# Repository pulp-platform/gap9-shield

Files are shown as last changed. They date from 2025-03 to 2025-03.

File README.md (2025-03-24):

# GAP9Shield: An AI-Capable Ultra-Low Power Module for Nano-Drones  

## Introduction  
The **GAP9Shield** is a state-of-the-art hardware module designed to enhance the performance of nano-drones, enabling advanced vision-based and ranging applications. Powered by the **GAP9 System-on-Chip (SoC)**, this platform delivers unparalleled AI processing capabilities and energy efficiency. With its compact design and cutting-edge features, GAP9Shield revolutionizes the potential of nano-drones, particularly for indoor environments and close-proximity interactions with humans.  

GAP9Shield mounted on a Craziflie 2.1

---

## Features and Specifications  

### Core Processor: GAP9 SoC  
- **Architecture**: 9-core RISC-V cluster with AI acceleration (NE16).  
- **Performance**: 15.6 GOPs for DSP, 32.2 GMACs for ML tasks.  
- **Energy Efficiency**: 330 µW/GOP.  
- **Dynamic Scaling**: Frequency up to 370 MHz, sleep power as low as 45 µW.  
- **Memory**:  
  - 1.6 MB L2 RAM and 2 MB embedded non-volatile memory.  
  - Additional 256 Mbit PSRAM and 512 Mbit Flash.  

### Camera: OV5647 Sensor  
- **Resolution**: 5 MP, supporting QSXGA to QVGA formats.  
- **Frame Rates**: Up to 120 fps (QVGA).  
- **Interface**: CSI2 single-line connectivity.  

### Connectivity: NINA-W102 Wi-Fi/BLE Module  
- **Processor**: ESP32 dual-core MCU.  
- **Wireless Capability**: 2.4 GHz Wi-Fi and Bluetooth.  
- **Throughput**: Up to 12 Mbps (UDP) with low power consumption.  

### Ranging System: 5D VL53L1 Array  
- **Directionality**: Covers right, left, front, back, and upward directions.  
- **Range**: Up to 400 cm with a sampling rate of 60 Hz.  

### Physical Characteristics  
- **Dimensions**: 50 mm x 27 mm (6-layer PCB).  
- **Weight**: Approx. 6 grams.  

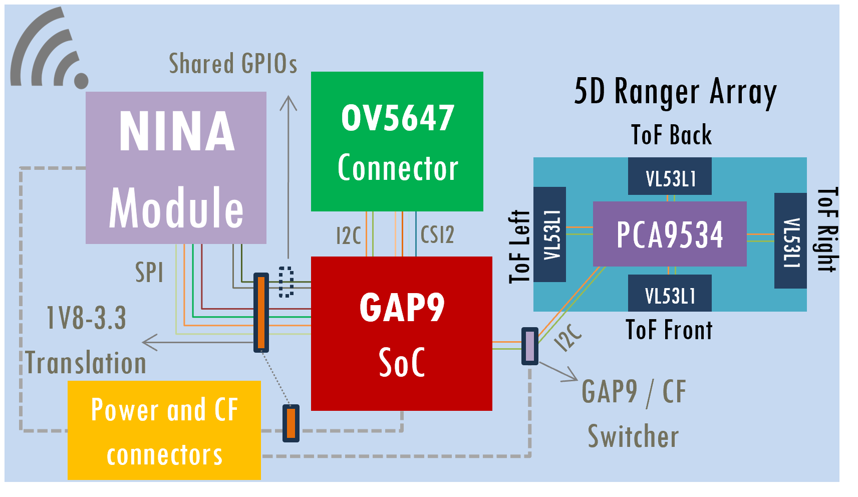
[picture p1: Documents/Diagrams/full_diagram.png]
Block diagram of GAP9Shield


---

## Key Advantages  

### Performance  
- 20% higher frame rate for RGB images compared to conventional AI-decks.  
- Optimized for AI workloads like YOLO object detection, MCL localization, and SLAM.  

### Energy Efficiency  
- Operates below 100 mW for most tasks.  
- Designed for extended flight durations with lightweight, power-efficient components.  

### Versatility  
- Compatible with high-definition cameras via MIPI CSI2.  
- Integrated Wi-Fi and BLE modules for seamless data streaming and communication.  

### Compact and Lightweight  
- 15% lighter and 30% smaller than comparable setups.  

---

## Applications  
The GAP9Shield is ideal for:  
- Obstacle avoidance in confined spaces.  
- Real-time object detection and mapping.  
- Greenhouse farming and industrial inspections.  
- Precise image recognition and navigation in cluttered environments.  

---

## Repository Organization
1. Hardware: Contains the hardware files for the shield.
1.1 gap9_deck_v2: Contains the design files (Altium) for the shield.
1.2 ToF-FrontBack: Contains the design files (Altium) for the ToF PCBs (front and back). These need to be mounted first and then soldered to the main PCB.
1.3 ToF-LeftRight: Contains the design files (Altium) for the ToF PCBs (Right and left). These need to be mounted first and then soldered to the main PCB.

2. Firmware: will contain firmware files (future release).

3. Documents: Contains the repository documentation.
3.1 Schematics: Main PCB and accesory PCB schematics in PDF format.
3.2 Pictures: Images/3D models of the shield.
3.3 Diagrams: GAP9shield diagrams.

---

## Acknowledges

If you use the **GAP9shield** in an academic or industrial context, please cite the following publication:

~~~~
@InProceedings{muller2024gap9shield,
author="M{\"u}ller, Hanna
and Kartsch, Victor
and Benini, Luca",
title="GAP9Shield: A 150GOPS AI-Capable Ultra-low Power Module for Vision and Ranging Applications on Nano-drones",
booktitle="European Robotics Forum 2024",
year="2024",
publisher="Springer Nature Switzerland",
address="Cham",
pages="292--297",
isbn="978-3-031-76424-0"
}
~~~~

# License

This project is open source. 

The files within the following folder (and subfolders) are released under Solderpad v0.51 (`SHL-0.51`) (see [LICENSE](LICENSE.txt)):

- `Hardware/`

The files within the following folder (and subfolders) are released under Creative Commons Attribution 4.0 International
License (`CC-BY-4.0`) (see [Documents/LICENSE](Documents/LICENSE)):

- `Documents/`

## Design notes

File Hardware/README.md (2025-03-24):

# GAP9Shield Hardware Documentation  

## Introduction  
This section provides all the necessary design files and resources for the hardware development of the **GAP9Shield**, a high-performance, low-power module designed for AI-driven applications on nano-drones. The GAP9Shield hardware is designed to optimize performance for nano-drones while maintaining a lightweight and compact form factor. Key features include:  
- **High-Performance ToF Sensors**: Enable obstacle avoidance and environmental mapping with high accuracy and low latency.  
- **GAP9 SoC Integration**: Ensures efficient processing for AI workloads with ultra-low power consumption.  
- **Easy Assembly**: Modular design allows for straightforward assembly and soldering.
 
 he hardware integrates multiple components, including the GAP9 SoC, a high-definition camera, and a 5D ranging array. The provided resources are organized into three folders, detailed below. 

---

## Folder Structure  

### 1. Hardware  
The `Hardware` folder contains all the design files necessary for the GAP9Shield and its associated subsystems. Each folder includes files created in **Altium Designer**, enabling straightforward editing and fabrication.

#### 1.1 gap9_deck_v2  
- **Description**: This folder contains the complete design files for the main shield PCB, integrating the GAP9 SoC, NINA-W102 Wi-Fi/BLE module, and OV5647 camera.  
- **Features**:  
  - 6-layer PCB with dimensions of 50mm x 27mm.  
  - Optimized layout for compactness and power efficiency.  
  - Interfaces for the ToF subsystems and external peripherals.

#### 1.2 ToF-FrontBack  
- **Description**: This folder contains design files for the **front** and **back** Time-of-Flight (ToF) sensor PCBs.  
- **Notes**:  
  - PCBs use the VL53L1 laser-based ToF sensors.  
  - These sensors enable precise distance measurements of up to 400 cm.  
  - These PCBs must be mounted first and soldered to the main PCB.

#### 1.3 ToF-LeftRight  
- **Description**: This folder contains design files for the **left** and **right** ToF sensor PCBs.  
- **Notes**:  
  - Utilizes the same VL53L1 ToF sensors as the front and back PCBs.  
  - These PCBs must also be mounted and soldered to the main PCB.  

---

For additional details, contact the development team.

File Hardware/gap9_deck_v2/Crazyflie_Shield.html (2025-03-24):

Altium customize

# Board Information Report

Date: | | 5/30/2022
Time: | | 4:37:14 PM
Elapsed Time: | | 00:00:00
Filename: | | C:\noOneDrive\FFG9_HW_CF_deck\gap9_deck\Crazyflie_Shield.PcbDoc
Units: | | mmmils

## Contents

Contents

Layer Information

Layer Information

Other

Pad Pwr/Gnd Expansion

## Layer Information

Layer | Arcs | Pads | Vias | Tracks | Texts | Fills | Regions | ComponentBodies
F.Cu | 3 | 179 | 0 | 306 | 0 | 0 | 7 | 0
Layer 1 | 0 | 0 | 0 | 14 | 0 | 0 | 1 | 0
Layer 2 | 0 | 0 | 0 | 53 | 0 | 0 | 5 | 0
B.Cu | 0 | 144 | 0 | 309 | 0 | 0 | 0 | 0
B.Adhes | 0 | 0 | 0 | 0 | 0 | 0 | 0 | 1
Top 3D Body | 0 | 0 | 0 | 28 | 0 | 0 | 0 | 7
Top Courtyard | 0 | 0 | 0 | 28 | 0 | 0 | 0 | 0
Top Assembly | 0 | 0 | 0 | 28 | 7 | 0 | 0 | 0
Eco1.User | 10 | 0 | 0 | 1830 | 13 | 0 | 0 | 0
Mechanical 12 | 0 | 0 | 0 | 12 | 0 | 0 | 0 | 0
Mechanical 13 | 0 | 0 | 0 | 100 | 0 | 0 | 0 | 44
Mechanical 15 | 0 | 0 | 0 | 222 | 0 | 0 | 0 | 0
Top Component Center | 0 | 0 | 0 | 14 | 0 | 0 | 0 | 0
Bottom Assembly | 0 | 0 | 0 | 4 | 1 | 0 | 0 | 0
Bottom Courtyard | 0 | 0 | 0 | 4 | 0 | 0 | 0 | 0
Bottom 3D Body | 0 | 0 | 0 | 4 | 0 | 0 | 0 | 1
Bottom Component Center | 0 | 0 | 0 | 2 | 0 | 0 | 0 | 0
Multi-Layer | 0 | 22 | 96 | 0 | 0 | 0 | 2 | 0
F.Paste | 0 | 0 | 0 | 0 | 0 | 0 | 0 | 0
F.SilkS | 5 | 0 | 0 | 35 | 55 | 0 | 0 | 0
F.Mask | 5 | 0 | 0 | 0 | 0 | 0 | 7 | 0
B.Mask | 0 | 0 | 0 | 0 | 0 | 0 | 0 | 0
B.SilkS | 7 | 0 | 0 | 61 | 85 | 0 | 0 | 0
B.Paste | 0 | 0 | 0 | 0 | 0 | 0 | 0 | 0
Drill Guide | 0 | 0 | 0 | 0 | 0 | 0 | 0 | 0
Edge.Cuts | 0 | 0 | 0 | 0 | 0 | 0 | 0 | 0
Drill Drawing | 0 | 0 | 0 | 0 | 0 | 0 | 0 | 0
Total | 30 | 345 | 96 | 3054 | 161 | 0 | 22 | 53

Back to top

## Other

Pad Pwr/Gnd Expansion | Count
0.2mm | 345
Total | 345

Back to top

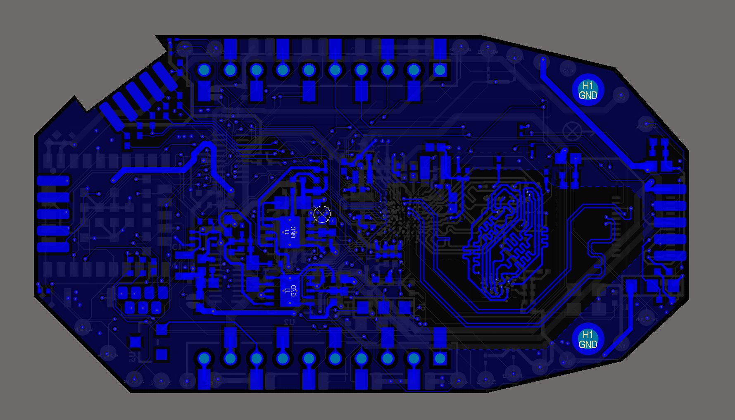
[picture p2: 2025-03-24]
Documents/Pictures/Renderings/2D/boton_2d.png

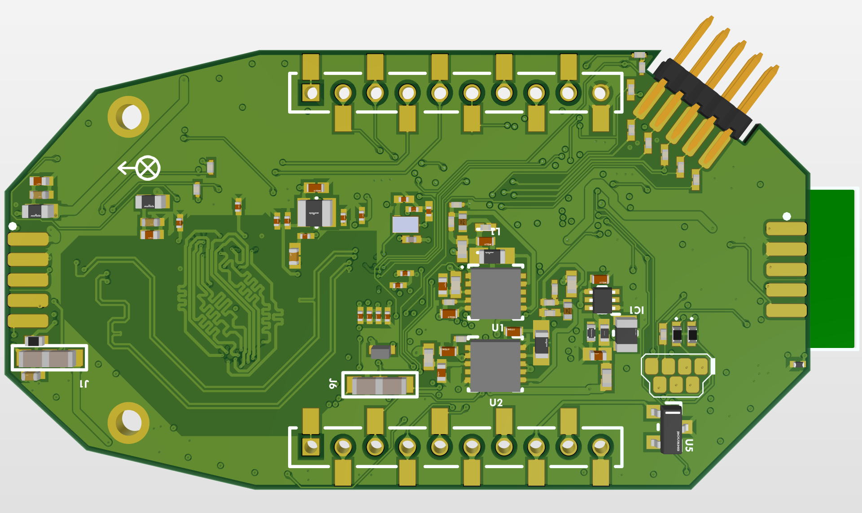
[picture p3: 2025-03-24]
Documents/Pictures/Renderings/3D/3D_bottom.png

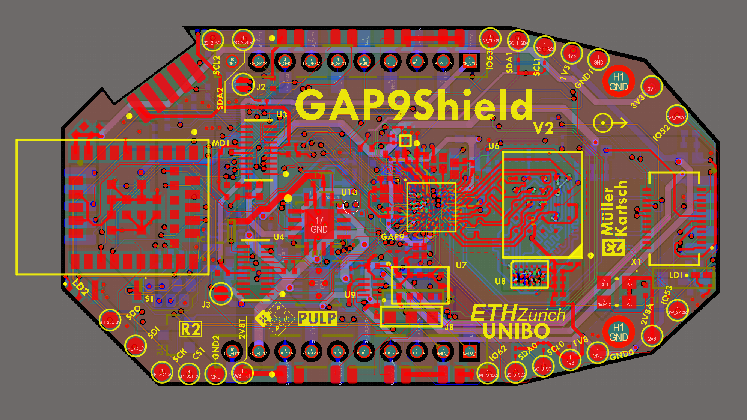
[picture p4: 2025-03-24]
Documents/Pictures/Renderings/2D/top_2d.png

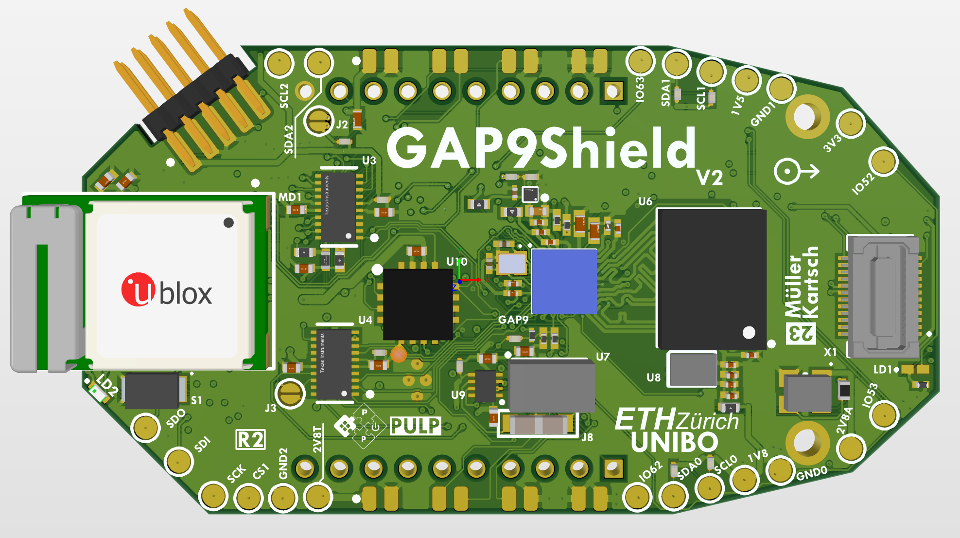
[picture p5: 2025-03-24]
Documents/Pictures/Renderings/3D/3D_top.png

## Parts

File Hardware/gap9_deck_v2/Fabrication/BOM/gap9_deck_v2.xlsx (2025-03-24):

Line # | Name | Description | Designator | Quantity | Manufacturer 1 | Manufacturer Part Number 1 | Manufacturer Lifecycle 1 | Supplier 1 | Supplier Part Number 1 | Supplier Unit Price 1 | Supplier Subtotal 1
 | 100K 1% 0201(0603) | 100K 0.05W 1% 0201 (0603 Metric) SMD | R37 | 1 | Panasonic | ERJ-1GNF1003C | Volume Production | Newark | 85Y7485 | 0.00371 | 0.00371
 | 150040GS73220 | LED | LD2 | 1 | Wurth Electronics | 150040GS73220 | Volume Production | Mouser | 710-150040GS73220 | 0.47271 | 0.47271
 | APHHS1005LSECK/J3-PF | LED | LD1 | 1 | Kingbright | APHHS1005LSECK/J3-PF | Volume Production | Arrow Electronics | APHHS1005LSECK/J3-PF | 0.40978 | 0.40978
 | APS256XXN-OBR-WA | No Description Available | U8 | 1 | Provided by client | Provided by client | Provided by client | Provided by client | Provided by client | Provided by client | Provided by client
 | BLM18HE152SN1D | Chip Ferrite Bead, 0603, 1500Ω @ 100MHz, 0.5Ω, 25%, 500mA | FB1, FB2 | 2 | Murata | BLM18HE152SN1D | Volume Production | Mouser | 81-BLM18HE152SN1D | 0.17611 | 0.35222
 | C1005X5R0J475K050BC | CAP CER 4.7UF 6.3V X5R 0402 | C24, C49, C55 | 3 | TDK | C1005X5R0J475K050BC | Volume Production | Newark | 79Y4179 | 0.07137 | 0.21411
 | CBL2012T1R0M | FIXED IND 1UH 950MA 195 MOHM SMD | L3 | 1 | Taiyo Yuden | CBL2012T1R0M | Not Recommended for New Design | Digi-Key | 587-1629-1-ND | 0.23172 | 0.23172
 | CBR02C200F5GAC | No Description Available | C39, C40 | 2 | KEMET | CBR02C200F5GAC | Volume Production | Newark | 96Y6792 | 0.11493 | 0.22987
 | CC0402KRX7R7BB103 | CAP CER 10000PF 16V X7R 0402 | C10, C11, C13 | 3 | Yageo | CC0402KRX7R7BB103 | Volume Production | Newark | 65R7669 | 0.00185 | 0.00556
 | CL03A105KP3NSNC | Cap Ceramic 1uF 10V X5R ±10% Pad SMD 0201 +85°C T/R | C23 | 1 | Samsung | CL03A105KP3NSNC | Volume Production | Digi-Key | 1276-6795-1-ND | 0.25953 | 0.25953
 | CL05A106MP5NUNC | CAP CER 10UF 10V X5R 0402 | C32, C63 | 2 | Samsung | CL05A106MP5NUNC | Not Recommended for New Design | Newark | 82AC9190 | 0.02873 | 0.05747
 | DNM |  | P1 | 1 | Do not mount | Do not mount | Do not mount | Do not mount | Do not mount | Do not mount | Do not mount
 | DNM |  | P2 | 1 | Do not mount | Do not mount | Do not mount | Do not mount | Do not mount | Do not mount | Do not mount
 | CRCW02014K99FKED |  | R3, R9 | 2 | Vishay Dale | CRCW02014K99FKED | Volume Production | Mouser | 71-CRCW02014K99FKED | 0.22245 | 0.4449
 | CRCW020110K0FNED |  | R1, R7, R11, R20, R22, R23, R27, R28, R45, R46, R47, R48, R49, R50, R51, R52, R54 | 17 | Vishay | CRCW020110K0FNED | Volume Production | Newark | 72W1407 | 0.00649 | 0.1103
 | CRCW020164K9FKED |  | R5 | 1 | Panasonic | ERJ-1GNF6492C | Volume Production | Digi-Key | P123116CT-ND | 0.09269 | 0.09269
 | CRCW020180K6FNED |  | R21 | 1 | Vishay | CRCW020180K6FNED | Volume Production | Digi-Key | 541-CRCW020180K6FNEDCT-ND | 0.09269 | 0.09269
 | CRCW0201200KFKED |  | R2, R8 | 2 | Vishay Dale | CRCW0201200KFKED | Volume Production | Newark | 84AH5178 | 0.13069 | 0.26138
 | CRCW0201220RFKED |  | R14, R15, R16, R17, R18, R19, R24 | 7 | Vishay Dale | CRCW0201220RFKED | Volume Production | Arrow Electronics | CRCW0201220RFKED | 0.13329 | 0.933
 | CRCW04020000Z0EDC | RES 0 OHM JUMPER 1/16W 0402 | R44 | 1 | Vishay | CRCW04020000Z0EDC | Volume Production | Mouser | 71-CRCW04020000Z0EDC | 0.09269 | 0.09269
 | DF30FC-24DS-0.4V(81) | Board Connector, 24 Contact(s), 2 Row(s), Female, Straight, 0.016 inch Pitch, Surface Mount Terminal, Locking, Black Insulator, Receptacle | X1 | 1 | Hirose | DF30FC-24DS-0.4V(81) | Volume Production | Mouser | 798-DF30FC24DS04V81 | 0.95469 | 0.95469
 | DFE201610E-4R7M=P2 | Shielded Wirewound Inductor 4.7uH 20% 1100mA 0.288Ω 0806 (2016) | L7 | 1 | Murata | DFE201610E-4R7M=P2 | Volume Production | Digi-Key | 490-18108-1-ND | 0.32441 | 0.32441
 | DNM |  | J2, J3 | 2 | Do not mount | Do not mount | Do not mount | Do not mount | Do not mount | Do not mount | Do not mount
 | DNM | 2x10 Pin 50mil Header | P3 | 1 | Do not mount | Do not mount | Do not mount | Do not mount | Do not mount | Do not mount | Do not mount
 | DNM | 2x10 Pin 50mil Header | P4 | 1 | Do not mount | Do not mount | Do not mount | Do not mount | Do not mount | Do not mount | Do not mount
 | DNM | Resistor | R12 | 1 | Do not mount | Do not mount | Do not mount | Do not mount | Do not mount | Do not mount | Do not mount
 | DNM | ToF PCBs (DNM) | ToF1, ToF2 | 2 | Do not mount | Do not mount | Do not mount | Do not mount | Do not mount | Do not mount | Do not mount
 | DNM | ToF PCBs (DNM) | ToF3, ToF4 | 2 | Do not mount | Do not mount | Do not mount | Do not mount | Do not mount | Do not mount | Do not mount
 | DS28E05R+T | EEPROM 1-Wire 112-BYTE | U5 | 1 | Maxim | DS28E05R+T | Volume Production | Mouser | 700-DS28E05R+T | 0.92688 | 0.92688
 | ECS-.327-5-16-TR | 32.768kHz Â±20ppm Crystal 9pF 90 kOhms 2-SMD, No Lead | Y3 | 1 | ECS International | ECS-.327-5-16-TR | Volume Production | Arrow Electronics | ECS-.327-5-16-TR | 0.5223 | 0.5223
 | ECS-240-10-47Q-CES-TR | 24MHz Â±10ppm Crystal 10pF 150 Ohms 4-SMD, No Lead | Y2 | 1 | ECS International | ECS-240-10-47Q-CES-TR | Volume Production | Arrow Electronics | ECS-240-10-47Q-CES-TR | 0.54399 | 0.54399
 | ERJ-1GN0R00C | RES SMD 0 OHM JUMPER 1/20W 0201 | R53 | 1 | Panasonic | ERJ-1GN0R00C | Volume Production | Newark | 41AC9823 | 0.00463 | 0.00463
 | ERJ-1GNF1003C | RES SMD 100K OHM 1% 1/20W 0201 | R40, R41, R42, R43 | 4 | Panasonic | ERJ-1GNF1003C | Volume Production | Newark | 85Y7485 | 0.00371 | 0.01483
 | ERJ-2RKF1002X | Chip Resistor, 10 KOhm, +/- 1%, 100 mW, -55 to 155 degC, 0402 (1005 Metric), RoHS, Tape and Reel | R4, R10, R25, R26, R29, R30, R31, R32, R33, R34, R35, R36, R38, R39 | 14 | Panasonic | ERJ-2RKF1002X | Volume Production | Newark | 85Y8054 | 0.00371 | 0.05191
 | GAP9_MC |  | GAP1 | 1 | Provided by client | Provided by client | Provided by client | Provided by client | Provided by client | Provided by client | Provided by client
 | GJM0335G2A6R0WB01D | Ceramic Capacitor 6pF ±0.05pF 100V X8G 0201 (0603 Metric) | C21, C22 | 2 | Murata | GJM0335G2A6R0WB01D | Volume Production | Mouser | 81-GJM0335G2A6R0WB1D | 0.27807 | 0.55613
 | GRM033C81A105ME05D | Chip Multilayer Ceramic Capacitors for General Purpose, 0201, 1.0uF, X6S, 22%, 20%, 10V | C59 | 1 | Murata | GRM033C81A105ME05D | Volume Production | Newark | 65AH6941 | 0.06766 | 0.06766
 | GRM033Z71C104KE14D | Chip Multilayer Ceramic Capacitors for General Purpose, 0201, 0.10uF, X7R, 15%, 10%, 16V | C25, C26, C27, C28, C29, C30, C31, C33, C34, C35, C36, C37, C38, C41, C42, C43, C45, C47, C50, C56, C60, C61, C62 | 23 | Murata | GRM033Z71C104KE14D | Volume Production | Newark | 63AK6700 | 0.00556 | 0.12791
 | GRM035R60J475ME15D | Chip Multilayer Ceramic Capacitors for General Purpose, 0201, 4.7uF, X5R, 15%, 20%, 6.3V | C44, C46 | 2 | Murata | GRM035R60J475ME15D | Volume Production | Mouser | 81-GRM035R60J475ME5D | 0.22245 | 0.4449
 | GRM1555C1H102JA01D | Chip Multilayer Ceramic Capacitors for General Purpose, 0402, 1000pF, C0G, 30ppm/°C, 5%, 50V | C1, C2, C3, C4, C5, C6, C7, C8, C9, C12, C14, C15, C16, C17, C18, C19, C20, C48, C51, C52, C53, C54, C57, C58 | 24 | Murata | GRM1555C1H102JA01D | Volume Production | Newark | 48Y4389 | 0.00834 | 0.20021
 | KC2520K25.0000C1GE00 | OSCILLATOR XO 25.000MHZ CMOS SMD | Y1 | 1 | Kyocera AVX | KC2520K25.0000C1GE00 | Volume Production | Mouser | 581-KC2520K25.0C1GE | 1.16 | 1.16
 | LQM18FN4R7M00D | FIXED IND 4.7UH 80MA 600 MOHM | L1, L2 | 2 | Murata | LQM18FN4R7M00D | Not Recommended for New Design | Arrow Electronics | LQM18FN4R7M00D | 0.17648 | 0.35296
 | MX25UM51245GXDI00 | NOR Flash Memory 512Mb 1.8V Octa I/O Serial 24-Pin BGA | U6 | 1 | Macronix | MX25UM51245GXDI00 |  | Digi-Key | 1092-1253-ND | 8.13 | 8.13
 | NINA-W102-00B-00 | STAND-ALONE MULTIRADIO MODULES | MD1 | 1 | u-blox | NINA-W102-01B | Volume Production | Mouser | 377-NINA-W102-02B | 7 | 7
 | PCA9534RGVR | Undefined or Miscellaneous | U10 | 1 | Texas Instruments | PCA9534RGVR | Volume Production | Arrow Electronics | PCA9534RGVR | 1.87 | 1.87
 | RC0201JR-070RL | RES SMD 0 OHM JUMPER 1/20W 0201 | R6, R13 | 2 | Yageo | RC0201JR-070RL | Volume Production | Newark | 59M5095 | 0.01576 | 0.15757
 | TC1303C-ZP0EMF | 500mA Synchronous Buck Regulator + 300mA LDO with Power-Good Output, Adjustable, 1.8V, 10-Pin DFN, Industrial Temperature | U1 | 1 | Microchip | TC1303C-ZP0EMF | Volume Production | Mouser | 579-TC1303C-ZP0EMF | 1.69 | 1.69
 | TC1303C-ZS0EMF | 500mA Synchronous Buck Regulator + 300mA LDO with Power-Good Output, Adjustable, 1.5V, 10-Pin DFN, Industrial Temperature | U2 | 1 | Microchip | TC1303C-ZS0EMF | Volume Production | Mouser | 579-TC1303C-ZS0EMF | 1.69 | 1.69
 | TPS62A01DRLR | Integrated Circuit | IC1 | 1 | Texas Instruments | TPS62A01DRLR | Unknown | Digi-Key | 296-TPS62A01DRLRCT-ND | 0.36148 | 0.36148
 | TPS22916CLYFPR | IC PWR SWITCH P-CHAN 1:1 4DSBGA | U11 | 1 | Texas Instruments | TPS22916CLYFPR | Volume Production | Arrow Electronics | TPS22916CLYFPR | 0.2307 | 0.2307
 | TS19-32-06-BK-70-1-SMT-TR-67 | Switch | S1 | 1 | CUI Devices | TS19-32-06-BK-70-1-SMT-TR-67 | Unknown | Digi-Key | 2223-TS19-32-06-BK-70-1-SMT-TR-67CT-ND | 0.40783 | 0.40783
 | TXB0108DQSR | IC TRNSLTR BIDIRECTIONAL 20USON | U3, U4 | 2 | Texas Instruments | TXB0108DQSR | Volume Production | Arrow Electronics | TXB0108DQSR | 1.55 | 3.1
 | TXS0102DQMR | Integrated Circuit | U9 | 1 | Texas Instruments | TXS0102DQMR | Volume Production | Arrow Electronics | TXS0102DQMR | 0.79768 | 0.79768
 | VL53L1CXV0FY/1 |  | U7 | 1 | STMicroelectronics | VL53L1CXV0FY/1 | Volume Production | Digi-Key | 497-17764-6-ND | 6.64 | 6.64

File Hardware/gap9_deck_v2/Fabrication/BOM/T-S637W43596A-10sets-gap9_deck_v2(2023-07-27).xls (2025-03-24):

PCBWay Bom Quotation, Product No.:T-S637W43596A
Item # | *Designator | *Qty | Manufacturer | *Mfg Part # | Description / Value | Vendor Part # | *Package/Footprint | Your Instructions / Notes | *Unit Price(10 sets) | *Total | *Delivery Time | *PCBWay Note | Customer Reply | PCBWay Update
1 | R37 | 1 | Panasonic | ERJ-1GNF1003C | 100K 1% 0201(0603)『 』100K 0.05W 1% 0201 (0603 Metric) SMD | Newark『 』85Y7485 | 0201 | Volume Production | $0.046 | $0.460
2 | LD2 | 1 | Wurth Elektronik | 150040GS73220 | 150040GS73220『 』LED | Mouser『 』710-150040GS73220 | 0402 | Volume Production | $1.098 | $10.980 | 7-10 Workdays
3 | LD1 | 1 | Kingbright | APHHS1005LSECK/J3-PF | APHHS1005LSECK/J3-PF『 』LED | Arrow Electronics『 』APHHS1005LSECK/J3-PF | 0402 | Volume Production | $0.558 | $5.580
4 | U8 | 1 | Provided by client | Provided by client | APS256XXN-OBR-WA『 』No Description Available | Provided by client『 』Provided by client |  | Provided by client |  |  |  | [Supplied by customer客供];
5 | FB1,FB2 | 2 | Murata | BLM18HE152SN1D | BLM18HE152SN1D『 』Chip Ferrite Bead, 0603, 1500Ω @ 100MHz, 0.5Ω, 25%, 500mA | Mouser『 』81-BLM18HE152SN1D | 0603 | Volume Production | $0.076 | $1.520
6 | C24,C49,C55 | 3 | TDK | C1005X5R0J475K050BC | C1005X5R0J475K050BC『 』CAP CER 4.7UF 6.3V X5R 0402 | Newark『 』79Y4179 | 0402 | Volume Production | $0.140 | $4.200
7 | L3 | 1 | Taiyo Yuden | CBL2012T1R0M | CBL2012T1R0M『 』FIXED IND 1UH 950MA 195 MOHM SMD | Digi-Key『 』587-1629-1-ND | 0805 | Not Recommended for New Design | $0.403 | $4.030 | 7-10 Workdays
8 | C39,C40 | 2 | KEMET | CBR02C200F5GAC | CBR02C200F5GAC『 』No Description Available | Newark『 』96Y6792 | 0201 | Volume Production | $0.231 | $4.620
9 | C10,C11,C13 | 3 | YAGEO | CC0402KRX7R7BB103 | CC0402KRX7R7BB103『 』CAP CER 10000PF 16V X7R 0402 | Newark『 』65R7669 | 0402 | Volume Production | $0.005 | $0.150
10 | C23 | 1 | Samsung | CL03A105KP3NSNC | CL03A105KP3NSNC『 』Cap Ceramic 1uF 10V X5R ±10% Pad SMD 0201 +85°C T/R | Digi-Key『 』1276-6795-1-ND | 0201 | Volume Production | $0.063 | $0.630
11 | C32,C63 | 2 | Samsung | CL05A106MP5NUNC | CL05A106MP5NUNC『 』CAP CER 10UF 10V X5R 0402 | Newark『 』82AC9190 | 0402 | Not Recommended for New Design | $0.033 | $0.660
12 | P1 | 1 | Do not mount | Do not mount | DNM | Do not mount『 』Do not mount |  | Do not mount |  |  |  | [DNP不要贴];
13 | P2 | 1 | Do not mount | Do not mount | DNM | Do not mount『 』Do not mount |  | Do not mount |  |  |  | [DNP不要贴];
14 | R3,R9 | 2 | Vishay Dale | CRCW02014K99FKED | CRCW02014K99FKED | Mouser『 』71-CRCW02014K99FKED | 0201 | Volume Production | $0.092 | $1.840
15 | R1,R7,R11,R20,R22,R23,R27,R28,R45,R46,R47,R48,R49,R50,R51,R52,R54 | 17 | Vishay Dale | CRCW020110K0FNED | CRCW020110K0FNED | Newark『 』72W1407 | 0201 | Volume Production | $0.016 | $2.720
16 | R5 | 1 | Panasonic | ERJ-1GNF6492C | CRCW020164K9FKED | Digi-Key『 』P123116CT-ND | 0201 | Volume Production | $0.046 | $0.460
17 | R21 | 1 | Vishay Dale | CRCW020180K6FNED | CRCW020180K6FNED | Digi-Key『 』541-CRCW020180K6FNEDCT-ND | 0201 | Volume Production | $0.092 | $0.920
18 | R2,R8 | 2 | Vishay Dale | CRCW0201200KFKED | CRCW0201200KFKED | Newark『 』84AH5178 | 0201 | Volume Production | $0.037 | $0.740
19 | R14,R15,R16,R17,R18,R19,R24 | 7 | Vishay Dale | CRCW0201220RFKED | CRCW0201220RFKED | Arrow Electronics『 』CRCW0201220RFKED | 0201 | Volume Production | $0.024 | $1.680
20 | R44 | 1 | Vishay Dale | CRCW04020000Z0EDC | CRCW04020000Z0EDC『 』RES 0 OHM JUMPER 1/16W 0402 | Mouser『 』71-CRCW04020000Z0EDC | 0402 | Volume Production | $0.025 | $0.250
21 | X1 | 1 | Hirose | DF30FC-24DS-0.4V(81) | DF30FC-24DS-0.4V(81)『 』Board Connector, 24 Contact(s), 2 Row(s), Female, Straight, 0.016 inch Pitch, Surface Mount Terminal, Locking, Black Insulator, Receptacle | Mouser『 』798-DF30FC24DS04V81 |  | Volume Production | $0.390 | $3.900
22 | L7 | 1 | Murata | DFE201610E-4R7M=P2 | DFE201610E-4R7M=P2『 』Shielded Wirewound Inductor 4.7uH 20% 1100mA 0.288Ω 0806 (2016) | Digi-Key『 』490-18108-1-ND |  | Volume Production | $0.341 | $3.410
23 | J2,J3 | 2 | Do not mount | Do not mount | DNM | Do not mount『 』Do not mount |  | Do not mount |  |  |  | [DNP不要贴];
24 | P3 | 1 | Do not mount | Do not mount | DNM『 』2x10 Pin 50mil Header | Do not mount『 』Do not mount |  | Do not mount |  |  |  | [DNP不要贴];
25 | P4 | 1 | Do not mount | Do not mount | DNM『 』2x10 Pin 50mil Header | Do not mount『 』Do not mount |  | Do not mount |  |  |  | [DNP不要贴];
26 | R12 | 1 | Do not mount | Do not mount | DNM『 』Resistor | Do not mount『 』Do not mount |  | Do not mount |  |  |  | [DNP不要贴];
27 | ToF1,ToF2 | 2 | Do not mount | Do not mount | DNM『 』ToF PCBs (DNM) | Do not mount『 』Do not mount |  | Do not mount |  |  |  | [DNP不要贴];
28 | ToF3,ToF4 | 2 | Do not mount | Do not mount | DNM『 』ToF PCBs (DNM) | Do not mount『 』Do not mount |  | Do not mount |  |  |  | [DNP不要贴];
29 | U5 | 1 | Maxim | DS28E05R+T | DS28E05R+T『 』EEPROM 1-Wire 112-BYTE | Mouser『 』700-DS28E05R+T |  | Volume Production | $1.249 | $12.490
30 | Y3 | 1 | ECS | ECS-.327-5-16-TR | ECS-.327-5-16-TR『 』32.768kHz Â±20ppm Crystal 9pF 90 kOhms 2-SMD, No Lead | Arrow Electronics『 』ECS-.327-5-16-TR |  | Volume Production | $1.008 | $10.080 | 7-10 Workdays
31 | Y2 | 1 | ECS | ECS-240-10-47Q-CES-TR | ECS-240-10-47Q-CES-TR『 』24MHz Â±10ppm Crystal 10pF 150 Ohms 4-SMD, No Lead | Arrow Electronics『 』ECS-240-10-47Q-CES-TR |  | Volume Production | $0.959 | $9.590 | 7-10 Workdays
32 | R53 | 1 | Panasonic | ERJ-1GN0R00C | ERJ-1GN0R00C『 』RES SMD 0 OHM JUMPER 1/20W 0201 | Newark『 』41AC9823 | 0201 | Volume Production | $0.046 | $0.460
33 | R40,R41,R42,R43 | 4 | Panasonic | ERJ-1GNF1003C | ERJ-1GNF1003C『 』RES SMD 100K OHM 1% 1/20W 0201 | Newark『 』85Y7485 | 0201 | Volume Production | $0.046 | $1.840
34 | R4,R10,R25,R26,R29,R30,R31,R32,R33,R34,R35,R36,R38,R39 | 14 | Panasonic | ERJ-2RKF1002X | ERJ-2RKF1002X『 』Chip Resistor, 10 KOhm, +/- 1%, 100 mW, -55 to 155 degC, 0402 (1005 Metric), RoHS, Tape and Reel | Newark『 』85Y8054 | 0402 | Volume Production | $0.023 | $3.220
35 | GAP1 | 1 | Provided by client | Provided by client | GAP9_MC | Provided by client『 』Provided by client |  | Provided by client |  |  |  | [Supplied by customer客供];
36 | C21,C22 | 2 | Murata | GJM0335G2A6R0WB01D | GJM0335G2A6R0WB01D『 』Ceramic Capacitor 6pF ±0.05pF 100V X8G 0201 (0603 Metric) | Mouser『 』81-GJM0335G2A6R0WB1D | 0201 | Volume Production | $0.638 | $12.760
37 | C59 | 1 | Murata | GRM033C81A105ME05D | GRM033C81A105ME05D『 』Chip Multilayer Ceramic Capacitors for General Purpose, 0201, 1.0uF, X6S, 22%, 20%, 10V | Newark『 』65AH6941 | 0201 | Volume Production | $0.147 | $1.470
38 | C25,C26,C27,C28,C29,C30,C31,C33,C34,C35,C36,C37,C38,C41,C42,C43,C45,C47,C50,C56,C60,C61,C62 | 23 | Murata | GRM033Z71C104KE14D | GRM033Z71C104KE14D『 』Chip Multilayer Ceramic Capacitors for General Purpose, 0201, 0.10uF, X7R, 15%, 10%, 16V | Newark『 』63AK6700 | 0201 | Volume Production | $0.019 | $4.370
39 | C44,C46 | 2 | Murata | GRM035R60J475ME15D | GRM035R60J475ME15D『 』Chip Multilayer Ceramic Capacitors for General Purpose, 0201, 4.7uF, X5R, 15%, 20%, 6.3V | Mouser『 』81-GRM035R60J475ME5D | 0201 | Volume Production | $0.194 | $3.880
40 | C1,C2,C3,C4,C5,C6,C7,C8,C9,C12,C14,C15,C16,C17,C18,C19,C20,C48,C51,C52,C53,C54,C57,C58 | 24 | Murata | GRM1555C1H102JA01D | GRM1555C1H102JA01D『 』Chip Multilayer Ceramic Capacitors for General Purpose, 0402, 1000pF, C0G, 30ppm/°C, 5%, 50V | Newark『 』48Y4389 | 0402 | Volume Production | $0.009 | $2.160
41 | Y1 | 1 | Kyocera AVX | KC2520K25.0000C1GE00 | KC2520K25.0000C1GE00『 』OSCILLATOR XO 25.000MHZ CMOS SMD | Mouser『 』581-KC2520K25.0C1GE |  | Volume Production | $1.706 | $17.060 | 7-10 Workdays
42 | L1,L2 | 2 | Murata | LQM18FN4R7M00D | LQM18FN4R7M00D『 』FIXED IND 4.7UH 80MA 600 MOHM | Arrow Electronics『 』LQM18FN4R7M00D | 0603 | Not Recommended for New Design | $0.216 | $4.320
43 | U6 | 1 | Macronix | MX25UM51245GXDI00 | MX25UM51245GXDI00『 』NOR Flash Memory 512Mb 1.8V Octa I/O Serial 24-Pin BGA | Digi-Key『 』1092-1253-ND |  |  | $10.634 | $106.340 | 7-10 Workdays
44 | MD1 | 1 | u-blox | NINA-W102-01B | NINA-W102-00B-00『 』STAND-ALONE MULTIRADIO MODULES | Mouser『 』377-NINA-W102-02B |  | Volume Production | $10.563 | $105.630 | 7-10 Workdays
45 | U10 | 1 | Texas Instruments | PCA9534RGVR | PCA9534RGVR『 』Undefined or Miscellaneous | Arrow Electronics『 』PCA9534RGVR |  | Volume Production | $2.561 | $25.610 | 7-10 Workdays
46 | R6,R13 | 2 | YAGEO | RC0201JR-070RL | RC0201JR-070RL『 』RES SMD 0 OHM JUMPER 1/20W 0201 | Newark『 』59M5095 | 0201 | Volume Production | $0.005 | $0.100
47 | U1 | 1 | Microchip | TC1303C-ZP0EMF | TC1303C-ZP0EMF『 』500mA Synchronous Buck Regulator + 300mA LDO with Power-Good Output, Adjustable, 1.8V, 10-Pin DFN, Industrial Temperature | Mouser『 』579-TC1303C-ZP0EMF |  | Volume Production | $3.078 | $30.780 | 7-10 Workdays
48 | U2 | 1 | Microchip | TC1303C-ZS0EMF | TC1303C-ZS0EMF『 』500mA Synchronous Buck Regulator + 300mA LDO with Power-Good Output, Adjustable, 1.5V, 10-Pin DFN, Industrial Temperature | Mouser『 』579-TC1303C-ZS0EMF |  | Volume Production | $2.739 | $27.390 | 7-10 Workdays
49 | IC1 | 1 | Texas Instruments | TPS62A01DRLR | TPS62A01DRLR『 』Integrated Circuit | Digi-Key『 』296-TPS62A01DRLRCT-ND |  | Unknown | $0.239 | $2.390
50 | U11 | 1 | Texas Instruments | TPS22916CLYFPR | TPS22916CLYFPR『 』IC PWR SWITCH P-CHAN 1:1 4DSBGA | Arrow Electronics『 』TPS22916CLYFPR |  | Volume Production | $0.381 | $3.810
51 | S1 | 1 | CUI Devices | TS19-32-06-BK-70-1-SMT-TR-67 | TS19-32-06-BK-70-1-SMT-TR-67『 』Switch | Digi-Key『 』2223-TS19-32-06-BK-70-1-SMT-TR-67CT-ND |  | Unknown | $0.611 | $6.110 | 7-10 Workdays
52 | U3,U4 | 2 | Texas Instruments | TXB0108DQSR | TXB0108DQSR『 』IC TRNSLTR BIDIRECTIONAL 20USON | Arrow Electronics『 』TXB0108DQSR |  | Volume Production | $0.953 | $19.060
53 | U9 | 1 | Texas Instruments | TXS0102DQMR | TXS0102DQMR『 』Integrated Circuit | Arrow Electronics『 』TXS0102DQMR |  | Volume Production | $0.625 | $6.250
54 | U7 | 1 | STMicroelectronics | VL53L1CXV0FY/1 | VL53L1CXV0FY/1 | Digi-Key『 』497-17764-6-ND |  | Volume Production | $5.390 | $53.900
 |  |  |  |  |  |  |  |  | Component Cost | $519.82

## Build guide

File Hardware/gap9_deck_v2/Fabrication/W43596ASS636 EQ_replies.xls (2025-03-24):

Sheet: DFM
Engineering Department Design For Manufacture and Engineering Confirmation Sheet
Item (项目) | Type (类型） | Description(描述） | Suggestion(建议) | PIC (图片) | Reply (回复) | Remark(备注) | Reply Brief (回复附图)
1 | 其他 | Like pic1, trace like pointed on top and bottom layers is just with 0.05MM,which is too small to produce and need to adjust with the space to 4mil. | A.We suggest to adjust the space to 4mil. | FIG1
2 | 其他 | Like pic2, some pads are too close to board outline,in order to avoid exposing copper, we suggest to cut copper for production. | A.OK to cut the copper to keep 0.2MM space to board outline. | FIG2
3 | 其他 | You required to panel, pls check panel like attached file is OK or not. | A.OK to panel like attached file.
 |  |  |  |  |  | Customer Approved by：
 |  |  |  |  |  | Name：
 |  |  |  |  |  | Tel：
 |  |  |  |  |  | Date：

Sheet: FIG1
返回（Return） DFM

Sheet: FIG2
返回（Return） DFM

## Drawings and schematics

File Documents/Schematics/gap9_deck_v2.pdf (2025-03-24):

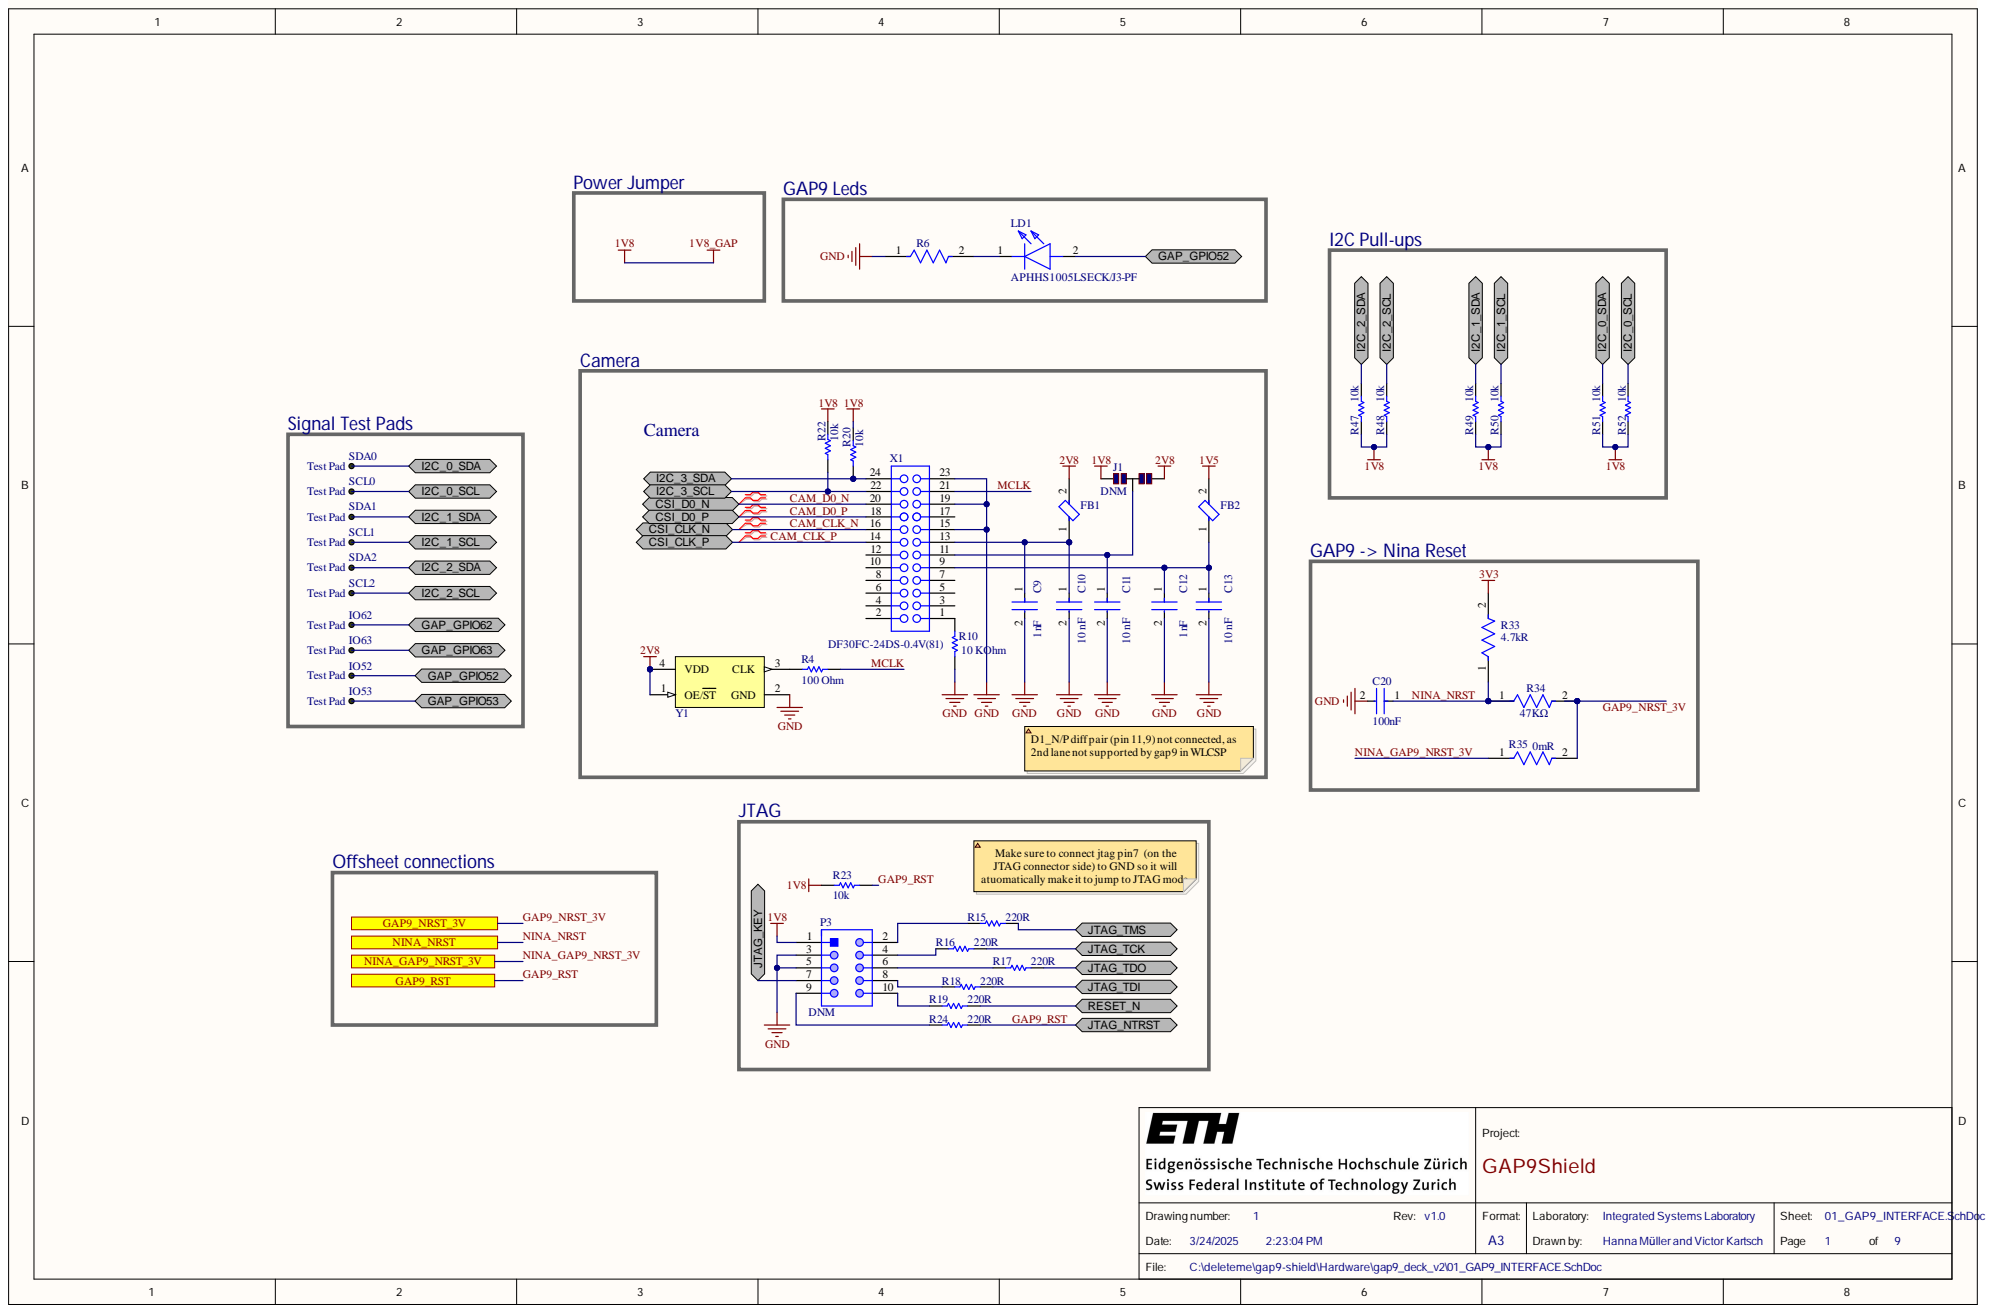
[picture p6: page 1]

D1_N/Pdiff pair (pin 11,9) not connected, as
2nd lane not supported by gap9 in WLCSP

Make sure to connect jtag pin7 (on the
JTAG connector side) to GND so it will
atuomatically make it to jump to JTAG mode

Project: GAP9Shield

Drawing number: 1 Rev: v1.0 Date: 2:23:04 PM | Format: A3 | Laboratory: Integrated Systems Laboratory Drawn by: Hanna Müller and VictorKartsch | Sheet: Page 1 of 9

C:\deleteme\gap9-shield\Hardware\gap9_deck_v2\01_GAP9_INTERFACE.SchDoc

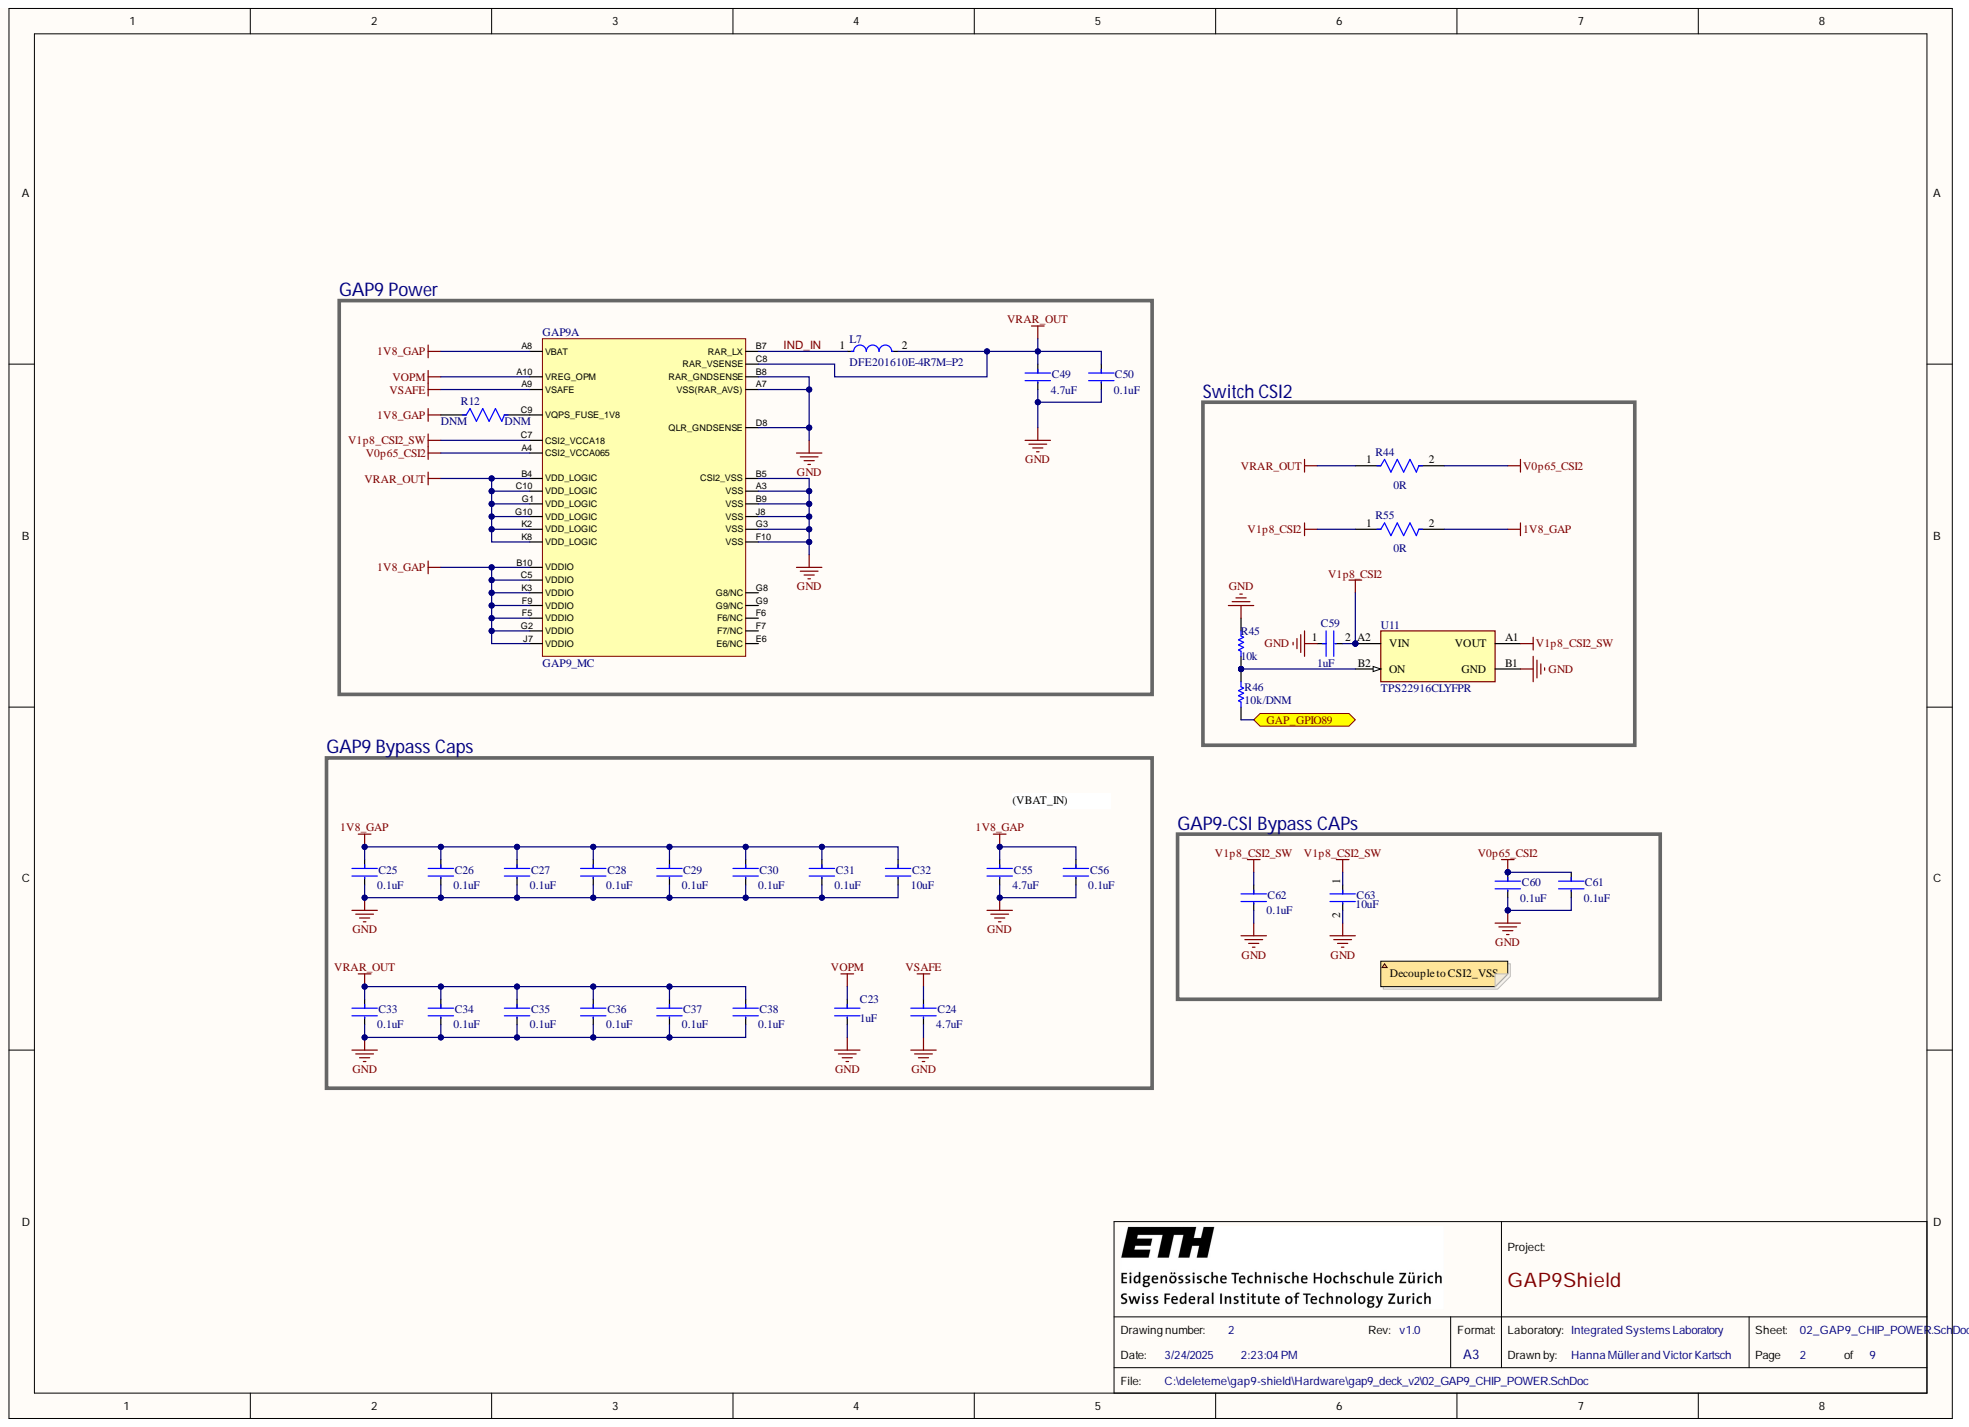
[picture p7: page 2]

VDDIO K3
VDDIO F5 VDDIO F9

VDDIO G2

Project: GAP9Shield

Drawing number: 2 Rev: v1.0 2:23:04 PM | Format: | Laboratory: Integrated Systems Laboratory | Sheet: Page 2 of 9

C:\deleteme\gap9-shield\Hardware\gap9_deck_v2\02_GAP9_CHIP_POWER.SchDoc

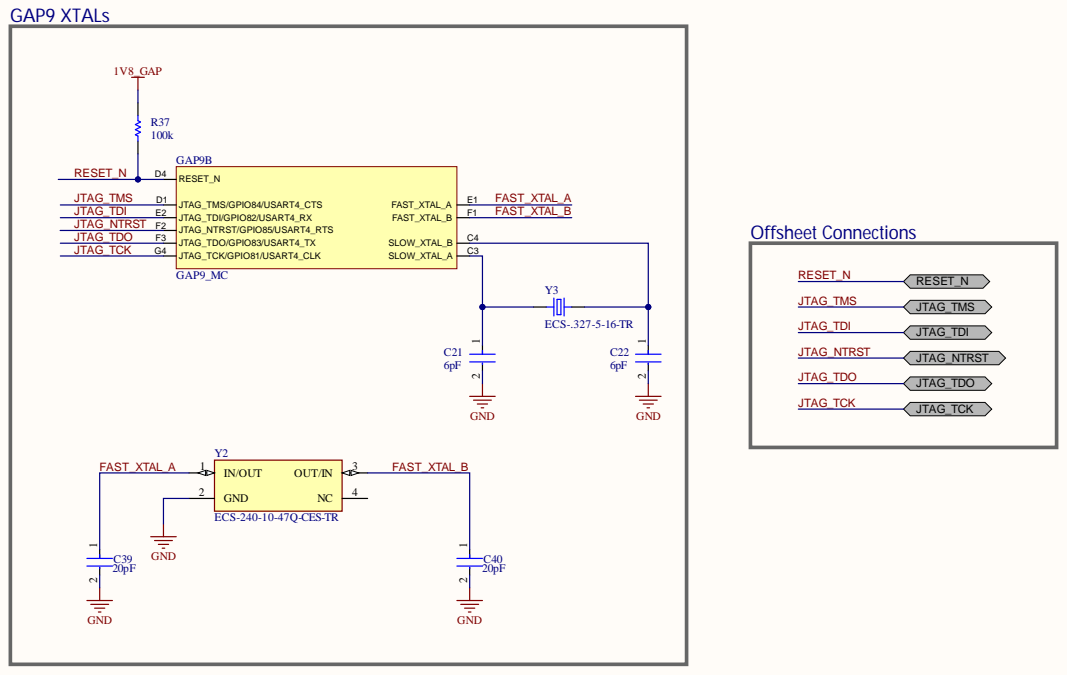
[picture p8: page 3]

Project: GAP9Shield

Drawing number: 3 Rev: v1.0 2:23:04 PM | Format: | Laboratory: Integrated Systems Laboratory | Sheet: Page 3 of 9

C:\deleteme\gap9-shield\Hardware\gap9_deck_v2\03_GAP9_CHIP_JTAG_XTALs.SchDoc

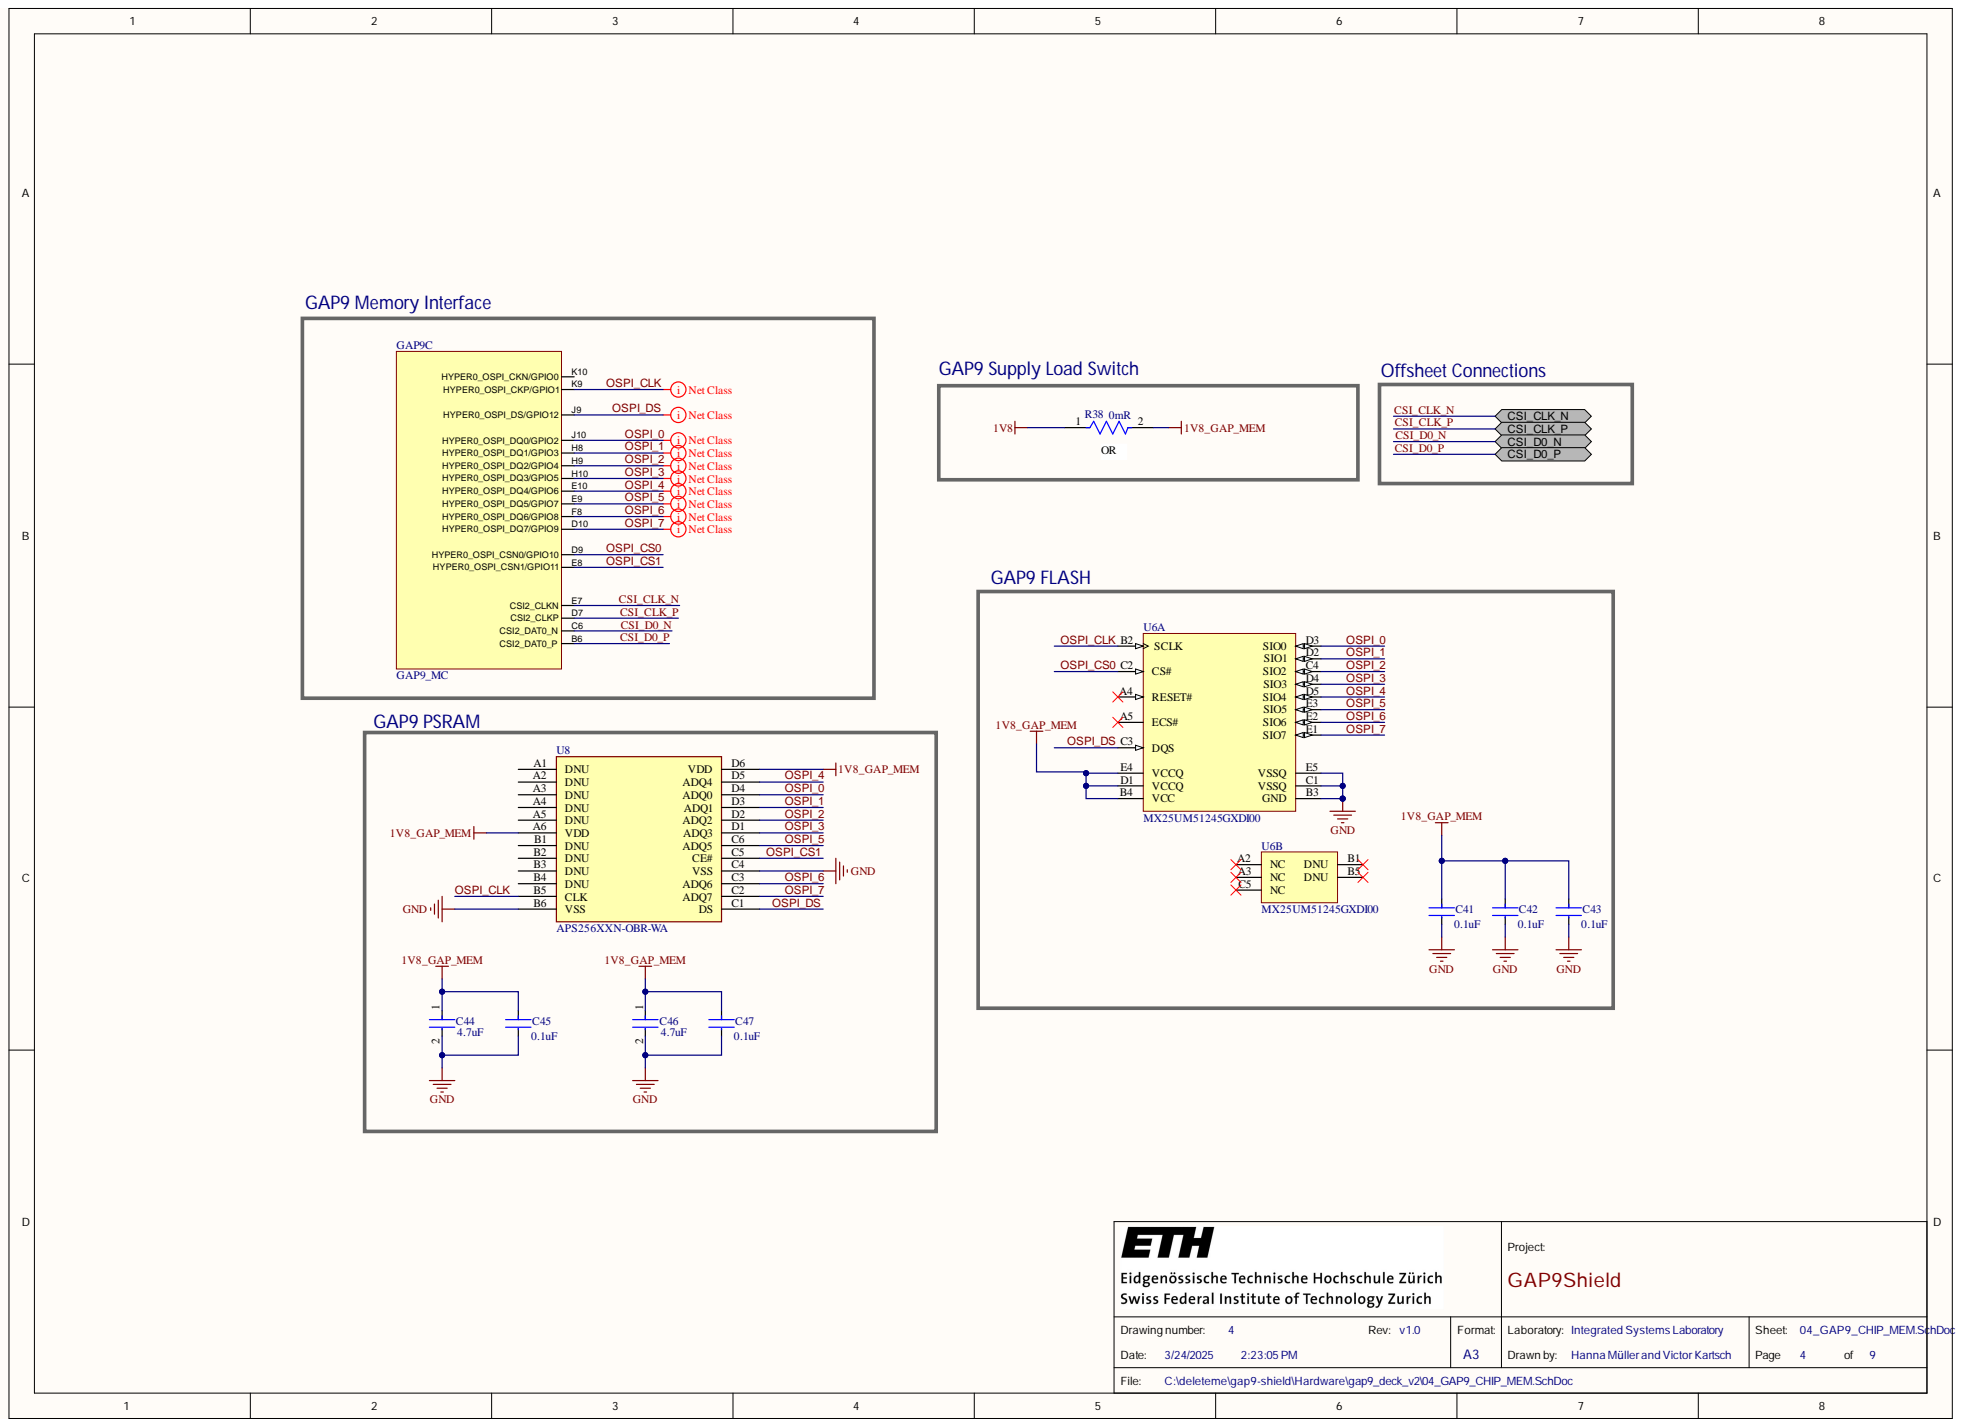
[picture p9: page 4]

P roj e c t: G A P 9 S h i e l d

D ra wi n g n u m b e r: 4 R e v : v 1 . 0 D a te : 3 /2 4/202 5 2 : 2 3 : 05 P M | F o rma t: A 3 | L a b o ra to ry : I n te g ra te d S y s tems L a b o ra to ry D ra wn b y : H a n n a M ü l l e r a n d V i c to r K a rts c h | S h e e t: 0 4_ G A P 9_ C H I P _ M E M. S P a g e 4 o f 9 | c

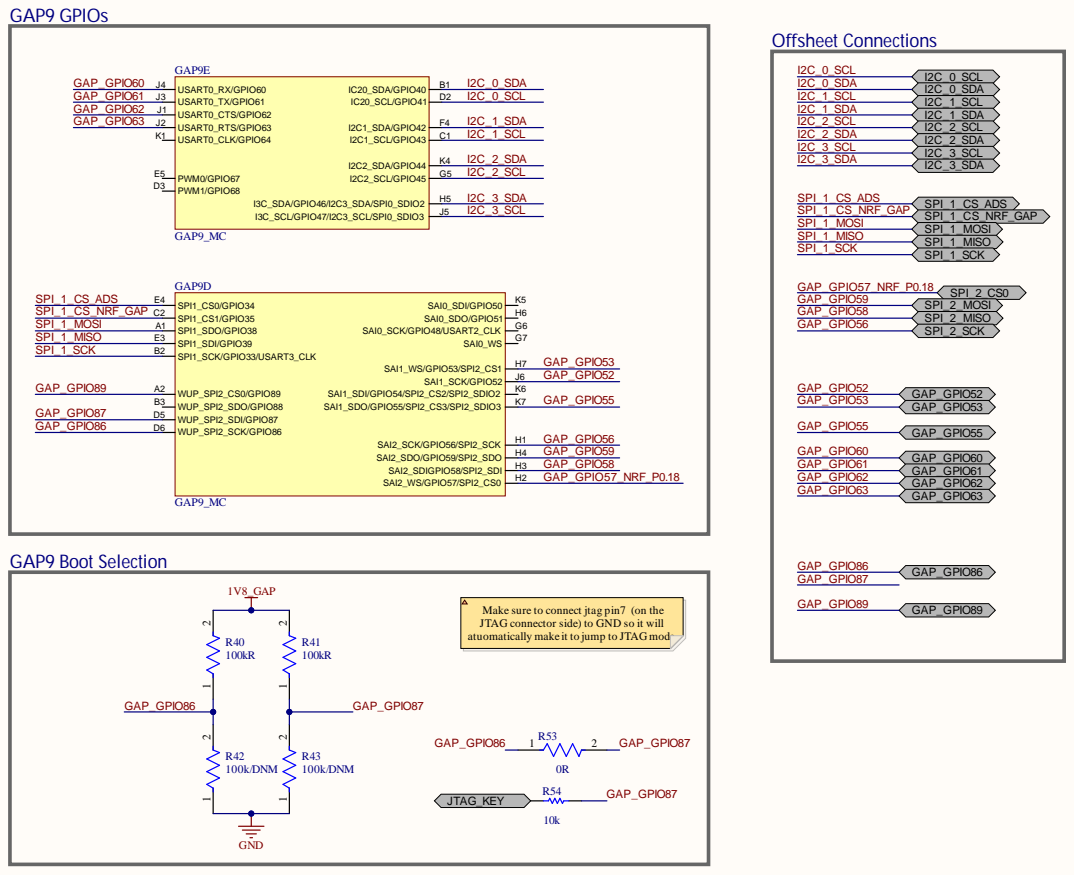
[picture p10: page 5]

P roj e c t: G A P 9 S h i e l d

D ra wi n g n u m b e r: 5 R e v : v 1 . 0 D a te : 3 /2 4/202 5 2 : 2 3 : 05 P M | F o rma t: A 3 | L a b o ra to ry : I n te g ra te d S y s tems L a b o ra to ry D ra wn b y : H a n n a M ü l l e r a n d V i c to r K a rts c h | S h e e t: 0 5_ G A P 9_ C H I P _ G P I O . S P a g e 5 o f 9 | c

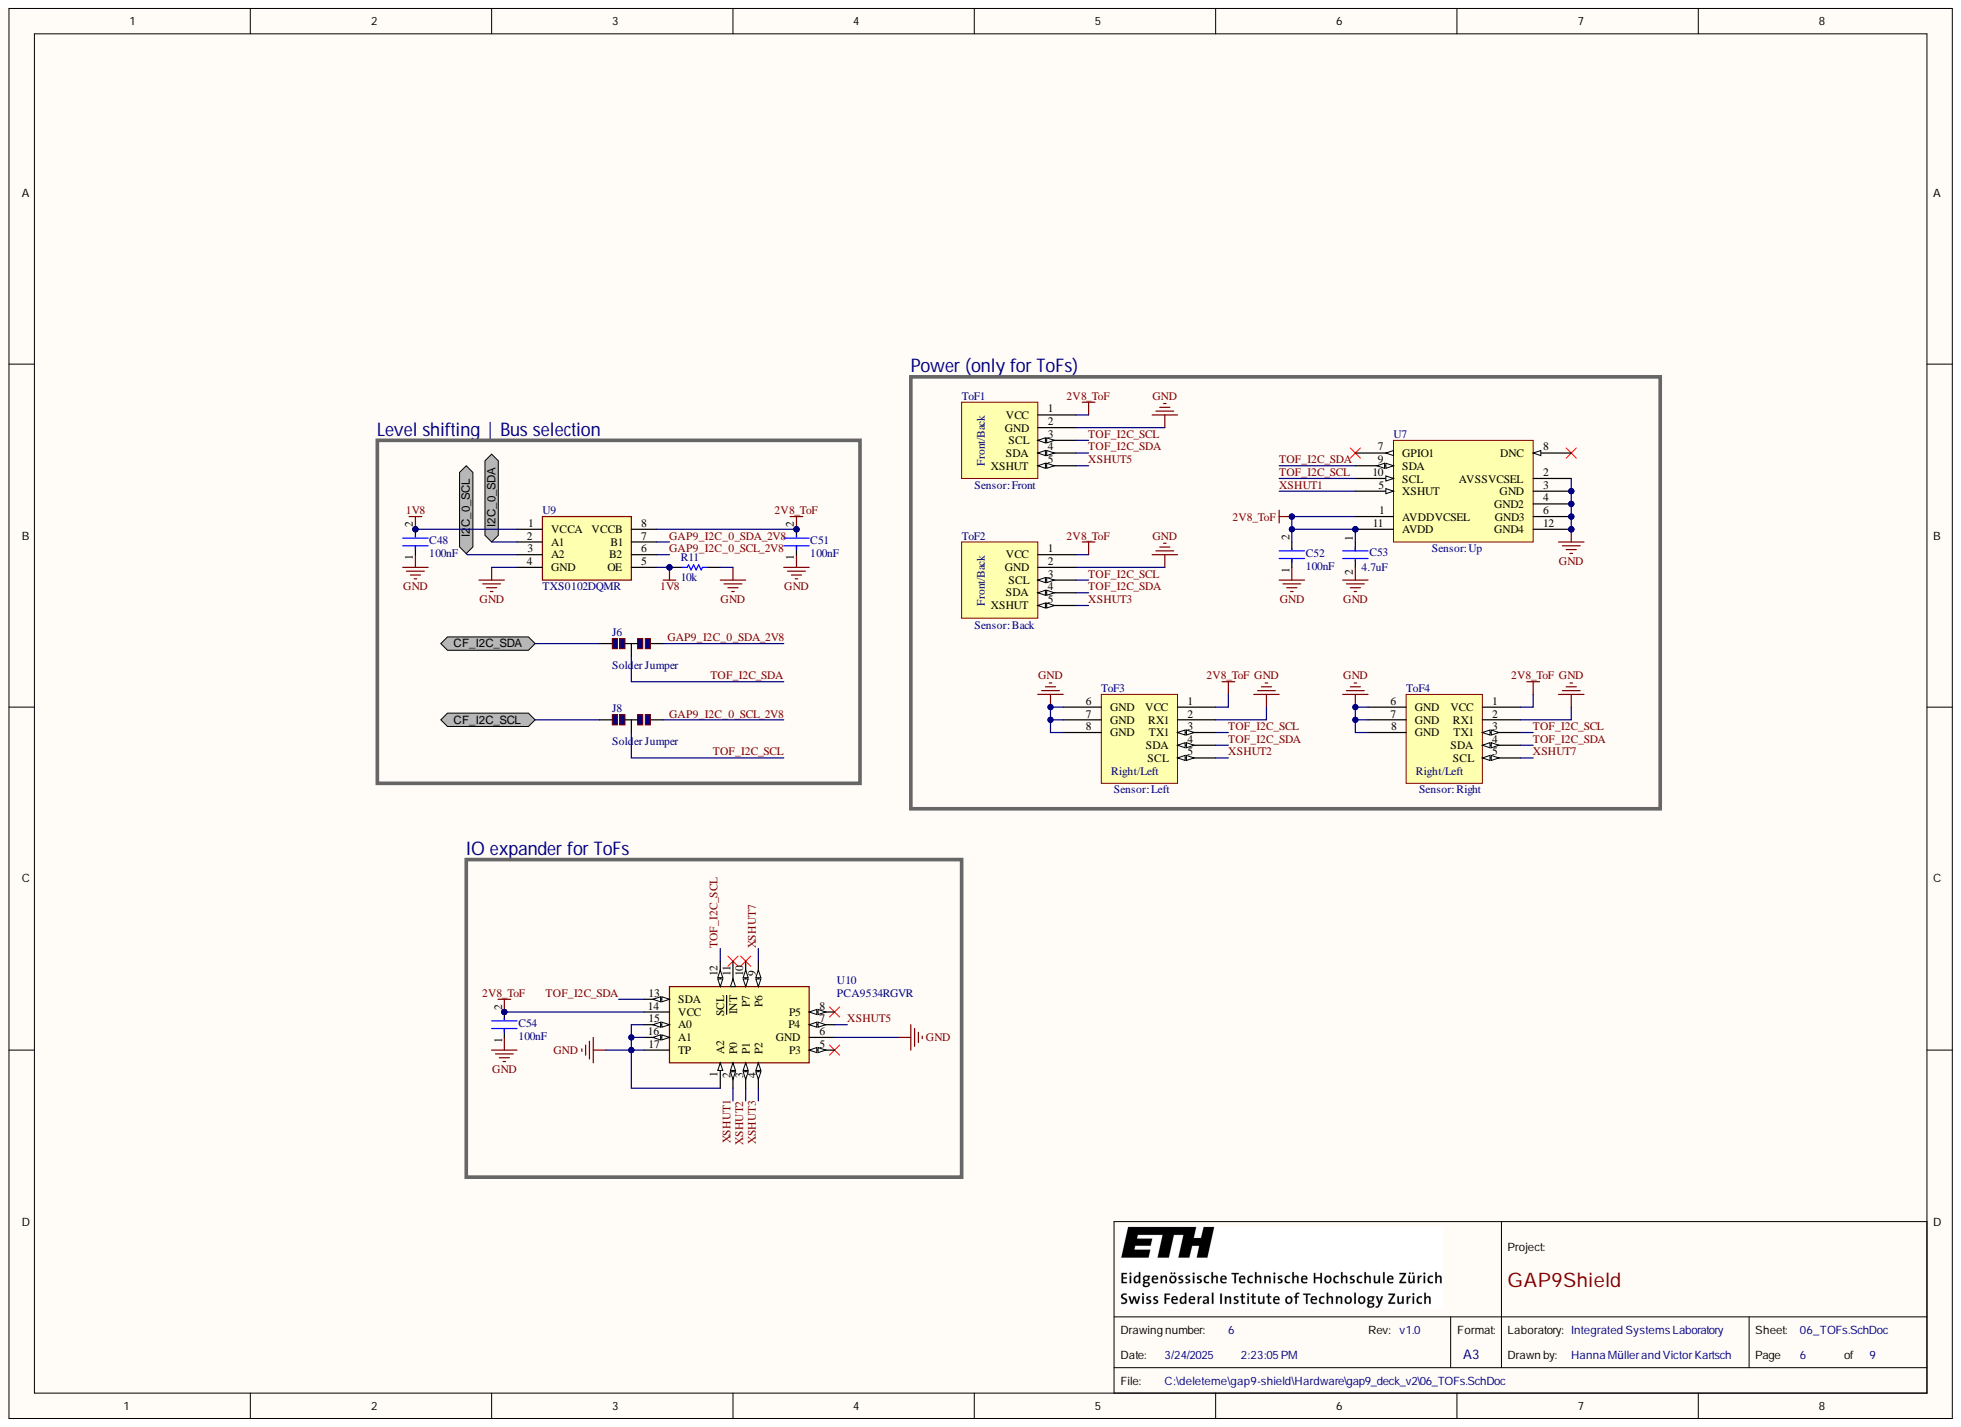
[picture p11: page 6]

Power (only for ToFs)

IO expander for ToFs

Project: GAP9Shield

Drawing number: 6 Rev: v1.0 2:23:05 PM | Format: | Laboratory: Integrated Systems Laboratory | Sheet: 06_TOFs.SchDoc Page 6 of 9

C:\deleteme\gap9-shield\Hardware\gap9_deck_v2\06_TOFs.SchDoc

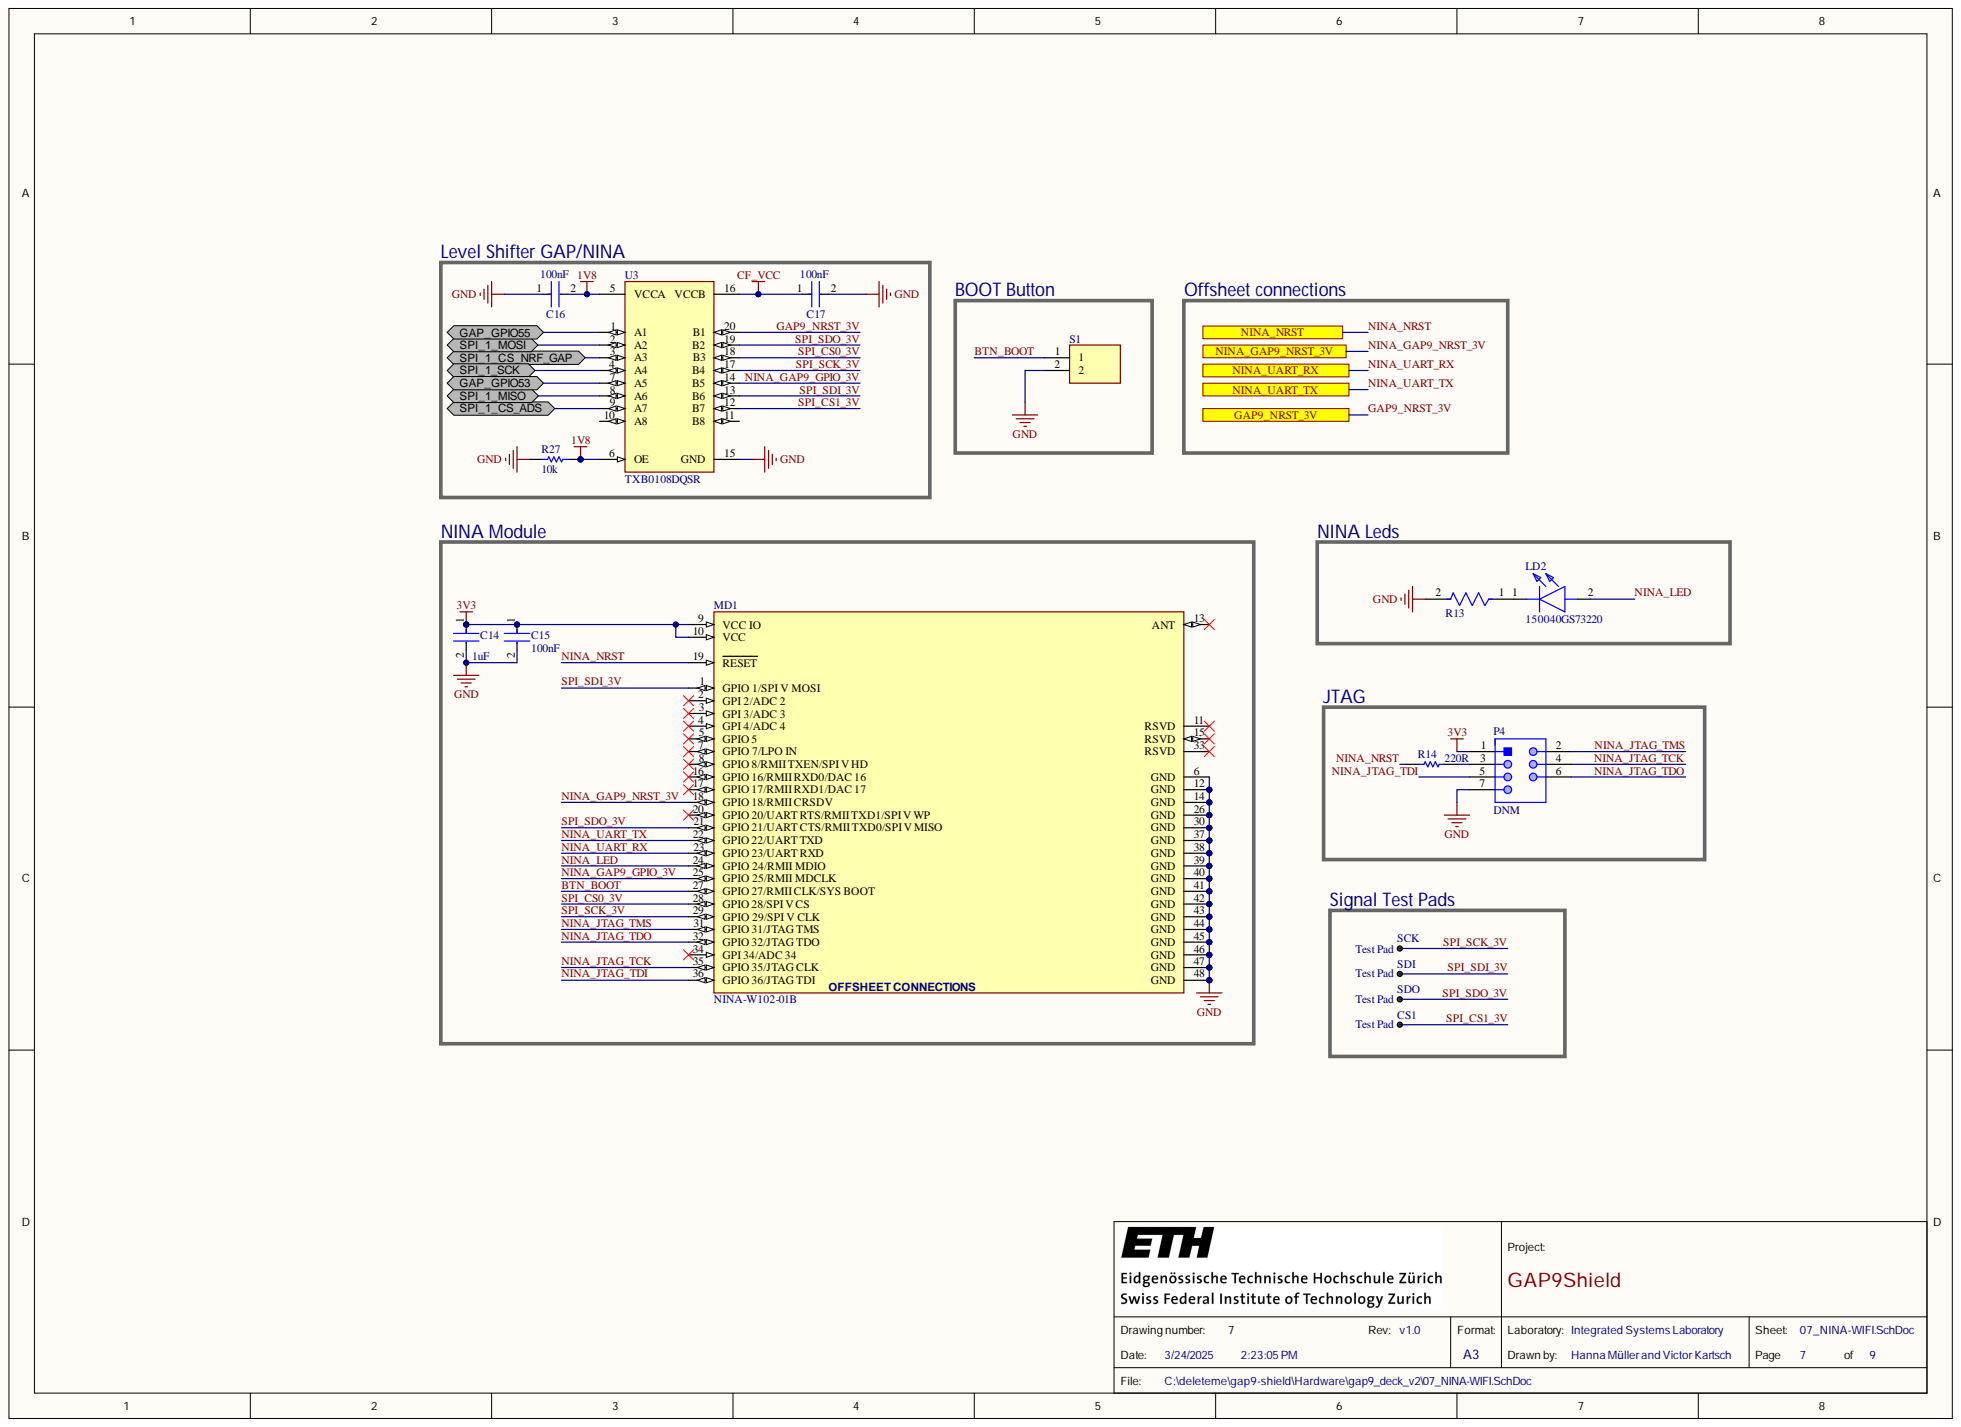
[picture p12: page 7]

Level Shifter GAP/NINA

GPIO 1/SPI V MOSI 1
GPI 2/ADC 2 2
GPI 3/ADC 3 3
GPI 4/ADC 4 4
GPIO 5 5
GPIO 7/LPO IN 7
GPIO 8/RMIITXEN/SPIV HD 8
GPIO 16/RMIIRXD0/DAC 16 16
GPIO 17/RMIIRXD1/DAC 17 17
GPIO 18/RMIICRSDV 18
GPIO 20/UART RTS/RMIITXD1/SPIV WP 20
GPIO 21/UART CTS/RMIITXD0/SPIV MISO 21
GPIO 22/UART TXD 22
GPIO 23/UART RXD 23
GPIO 24/RMII MDIO 24
GPIO 25/RMII MDCLK 25
GPIO 27/RMIICLK/SYS BOOT 27
GPIO 28/SPIV CS 28
GPIO 29/SPI V CLK 29
GPIO 31/JTAG TMS 31
GPIO 32/JTAG TDO 32
GPI 34/ADC 34 34
GPIO 35/JTAG CLK 35
GPIO 36/JTAG TDI 36

Project: GAP9Shield

Drawing number: 7 Rev: v1.0 2:23:05 PM | Format: | Laboratory: Integrated Systems Laboratory | Sheet: 07_NINA-WIFI.SchDoc Page 7 of 9

C:\deleteme\gap9-shield\Hardware\gap9_deck_v2\07_NINA-WIFI.SchDoc

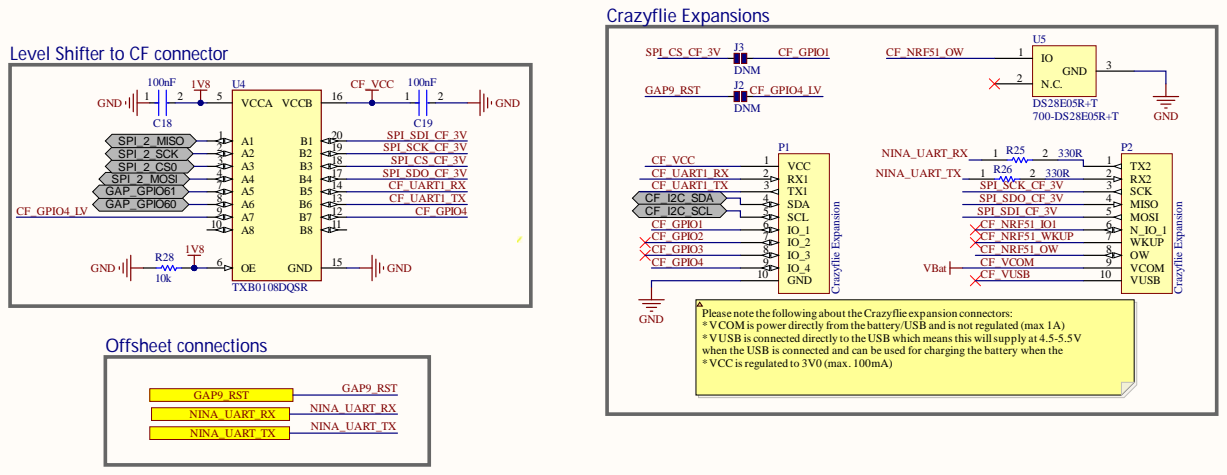
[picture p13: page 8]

Level Shifter to CF connector

Please note the following about theCrazyflie expansion connectors:
*VCOM is power directly from the battery/USB and is not regulated (max 1A)
*VUSB is connected directly to theUSB which meansthis willsupply at 4.5-5.5V
when the USB is connected and can be used for charging the battery when the
*VCC isregulated to 3V0 (max. 100mA)

Project: GAP9Shield

Drawing number: 8 Rev: v1.0 2:23:06 PM | Format: | Laboratory: Integrated Systems Laboratory | Sheet: 08_CF_INTERFACE.SchDoc Page 8 of 9

C:\deleteme\gap9-shield\Hardware\gap9_deck_v2\08_CF_INTERFACE.SchDoc

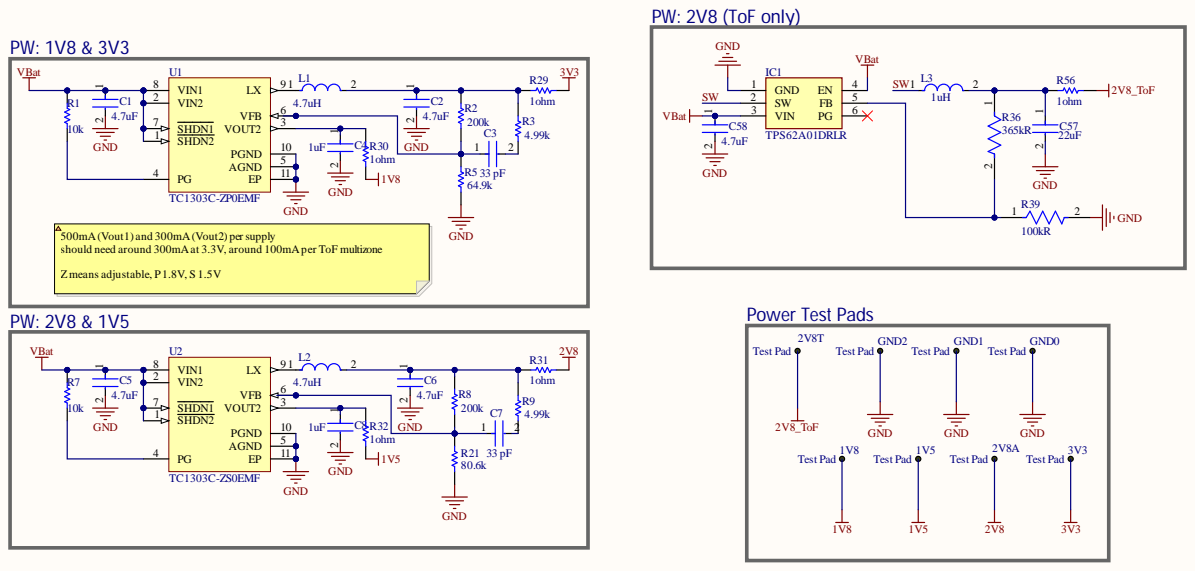
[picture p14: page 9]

P roj e c t: G A P 9 S h i e l d

D ra wi n g n u m b e r: 9 R e v : v 1 . 0 D a te : 3 /2 4/202 5 2 : 2 3 : 06 P M | F o rma t: A 3 | L a b o ra to ry : I n te g ra te d S y s tems L a b o ra to ry D ra wn b y : H a n n a M ü l l e r a n d V i c to r K a rts c h | S h e e t: 0 9_ P O W E R . S c h D o c P a g e 9 o f 9

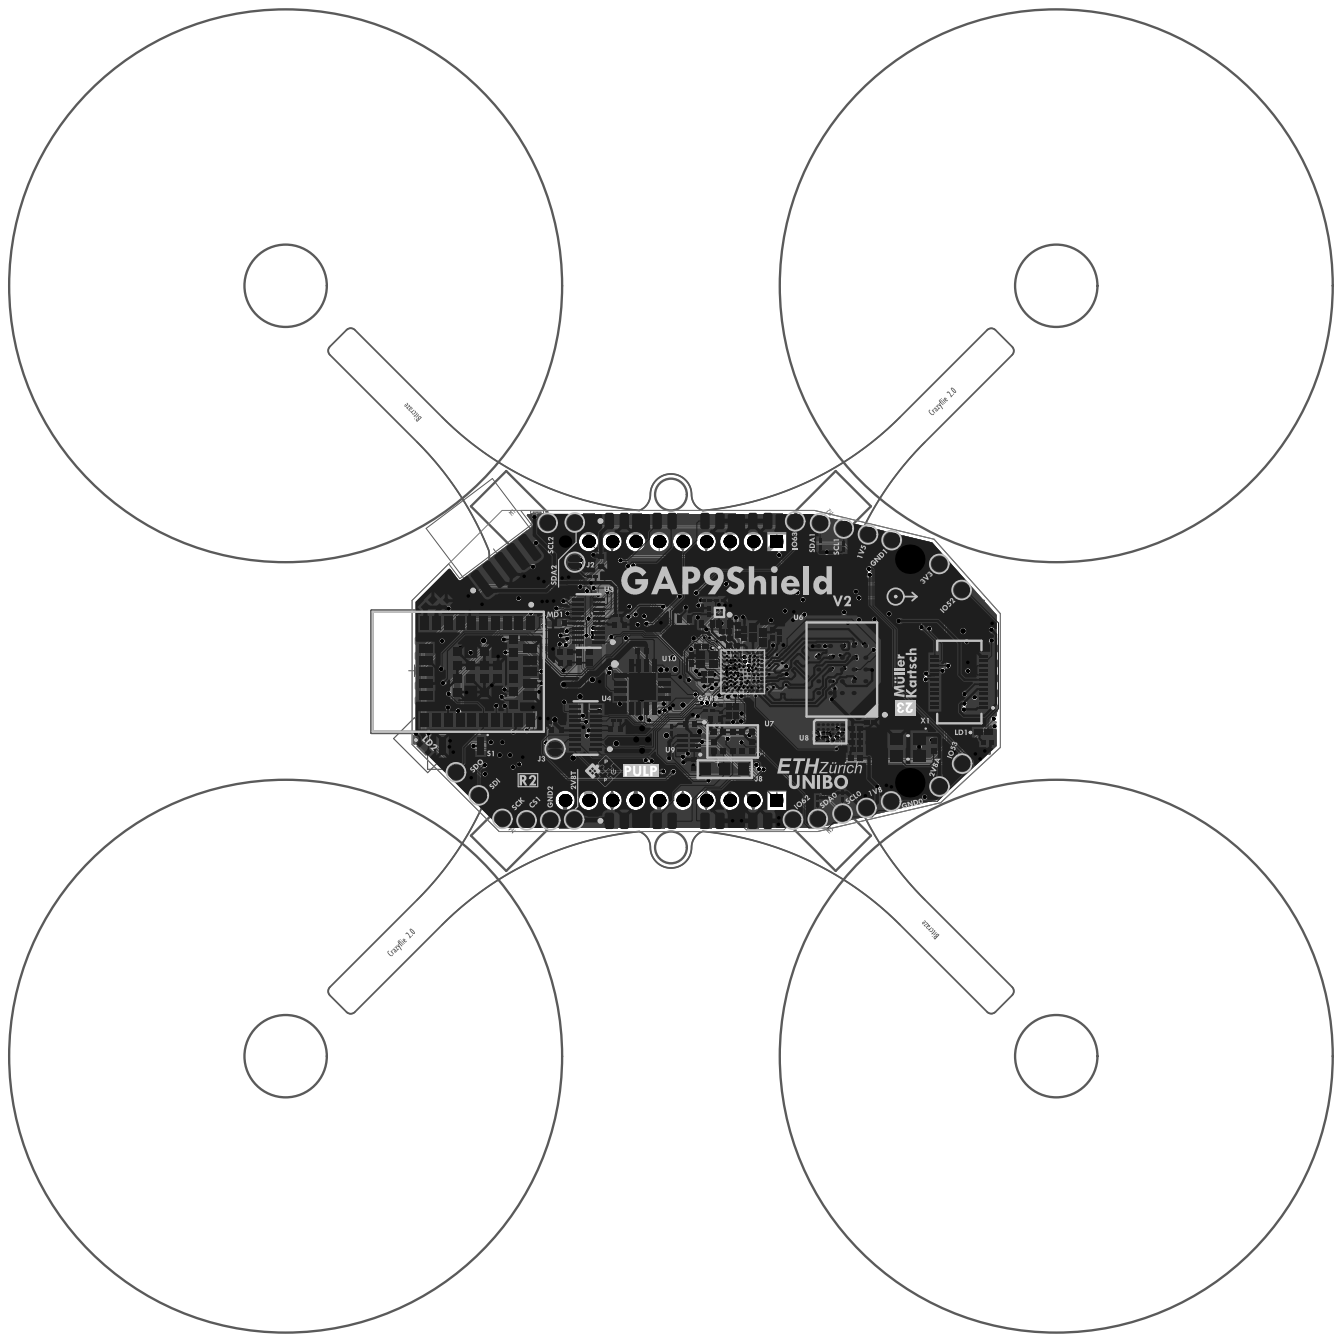
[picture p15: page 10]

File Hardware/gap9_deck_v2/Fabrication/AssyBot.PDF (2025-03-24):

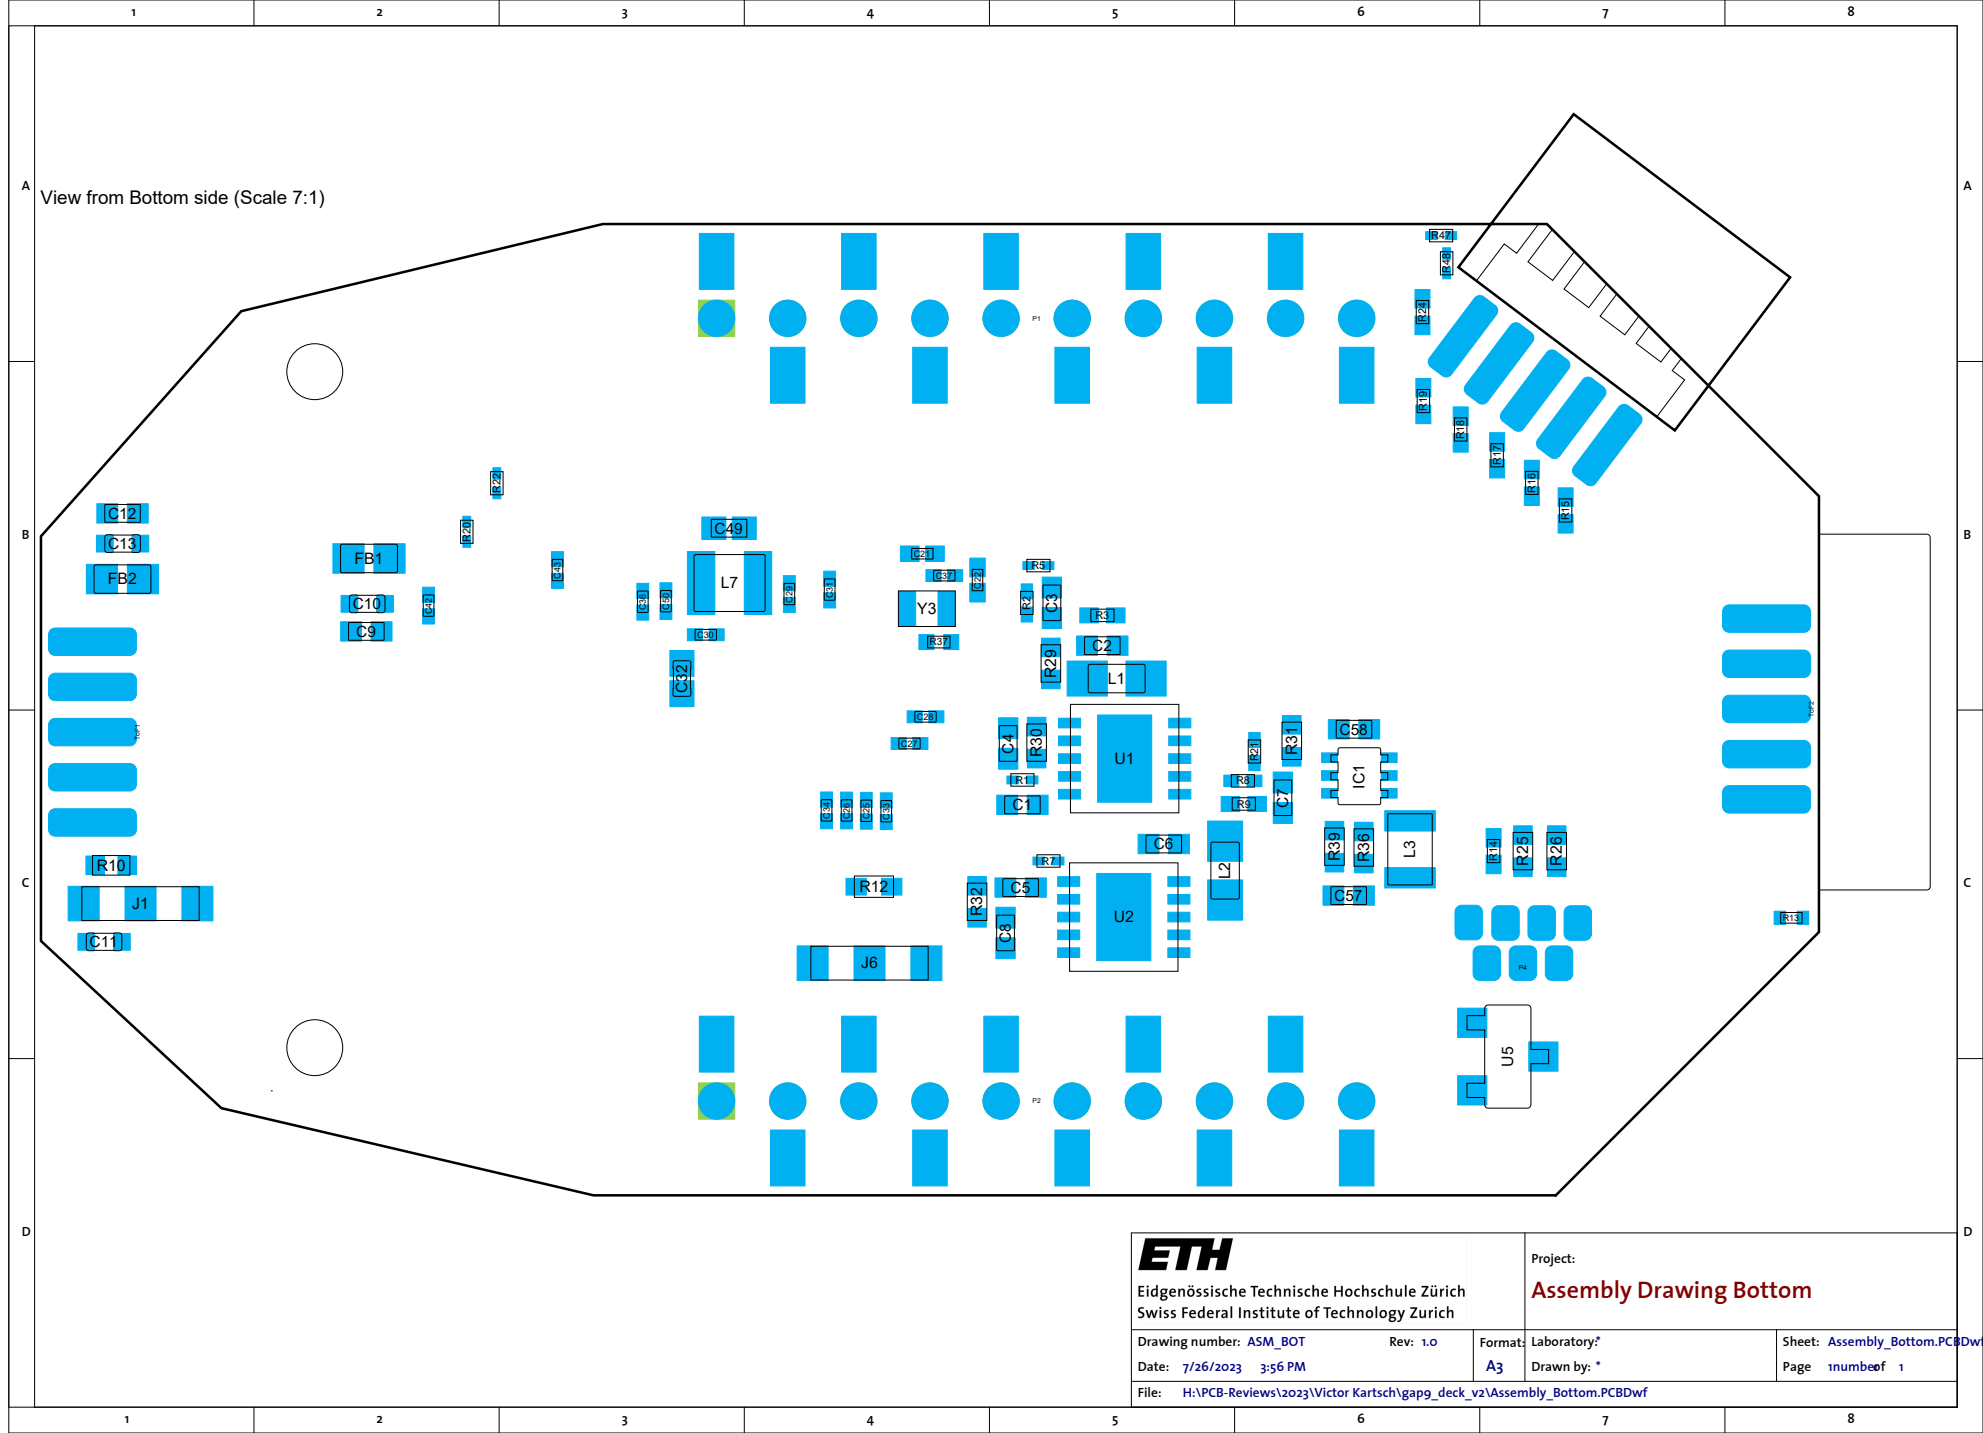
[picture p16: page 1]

View from Bottom side (Scale 7:1)

Project: Assembly Drawing Bottom

Drawing number: ASM_BOT Rev: 1.0 Date: 7/26/2023 3:56 PM | Format: A3 | Laboratory:* Drawn by: * | Sheet: Assembly_Bottom.PCBDwf Page 1numberof 1

H:\PCB-Reviews\2023\Victor Kartsch\gap9_deck_v2\Assembly_Bottom.PCBDwf

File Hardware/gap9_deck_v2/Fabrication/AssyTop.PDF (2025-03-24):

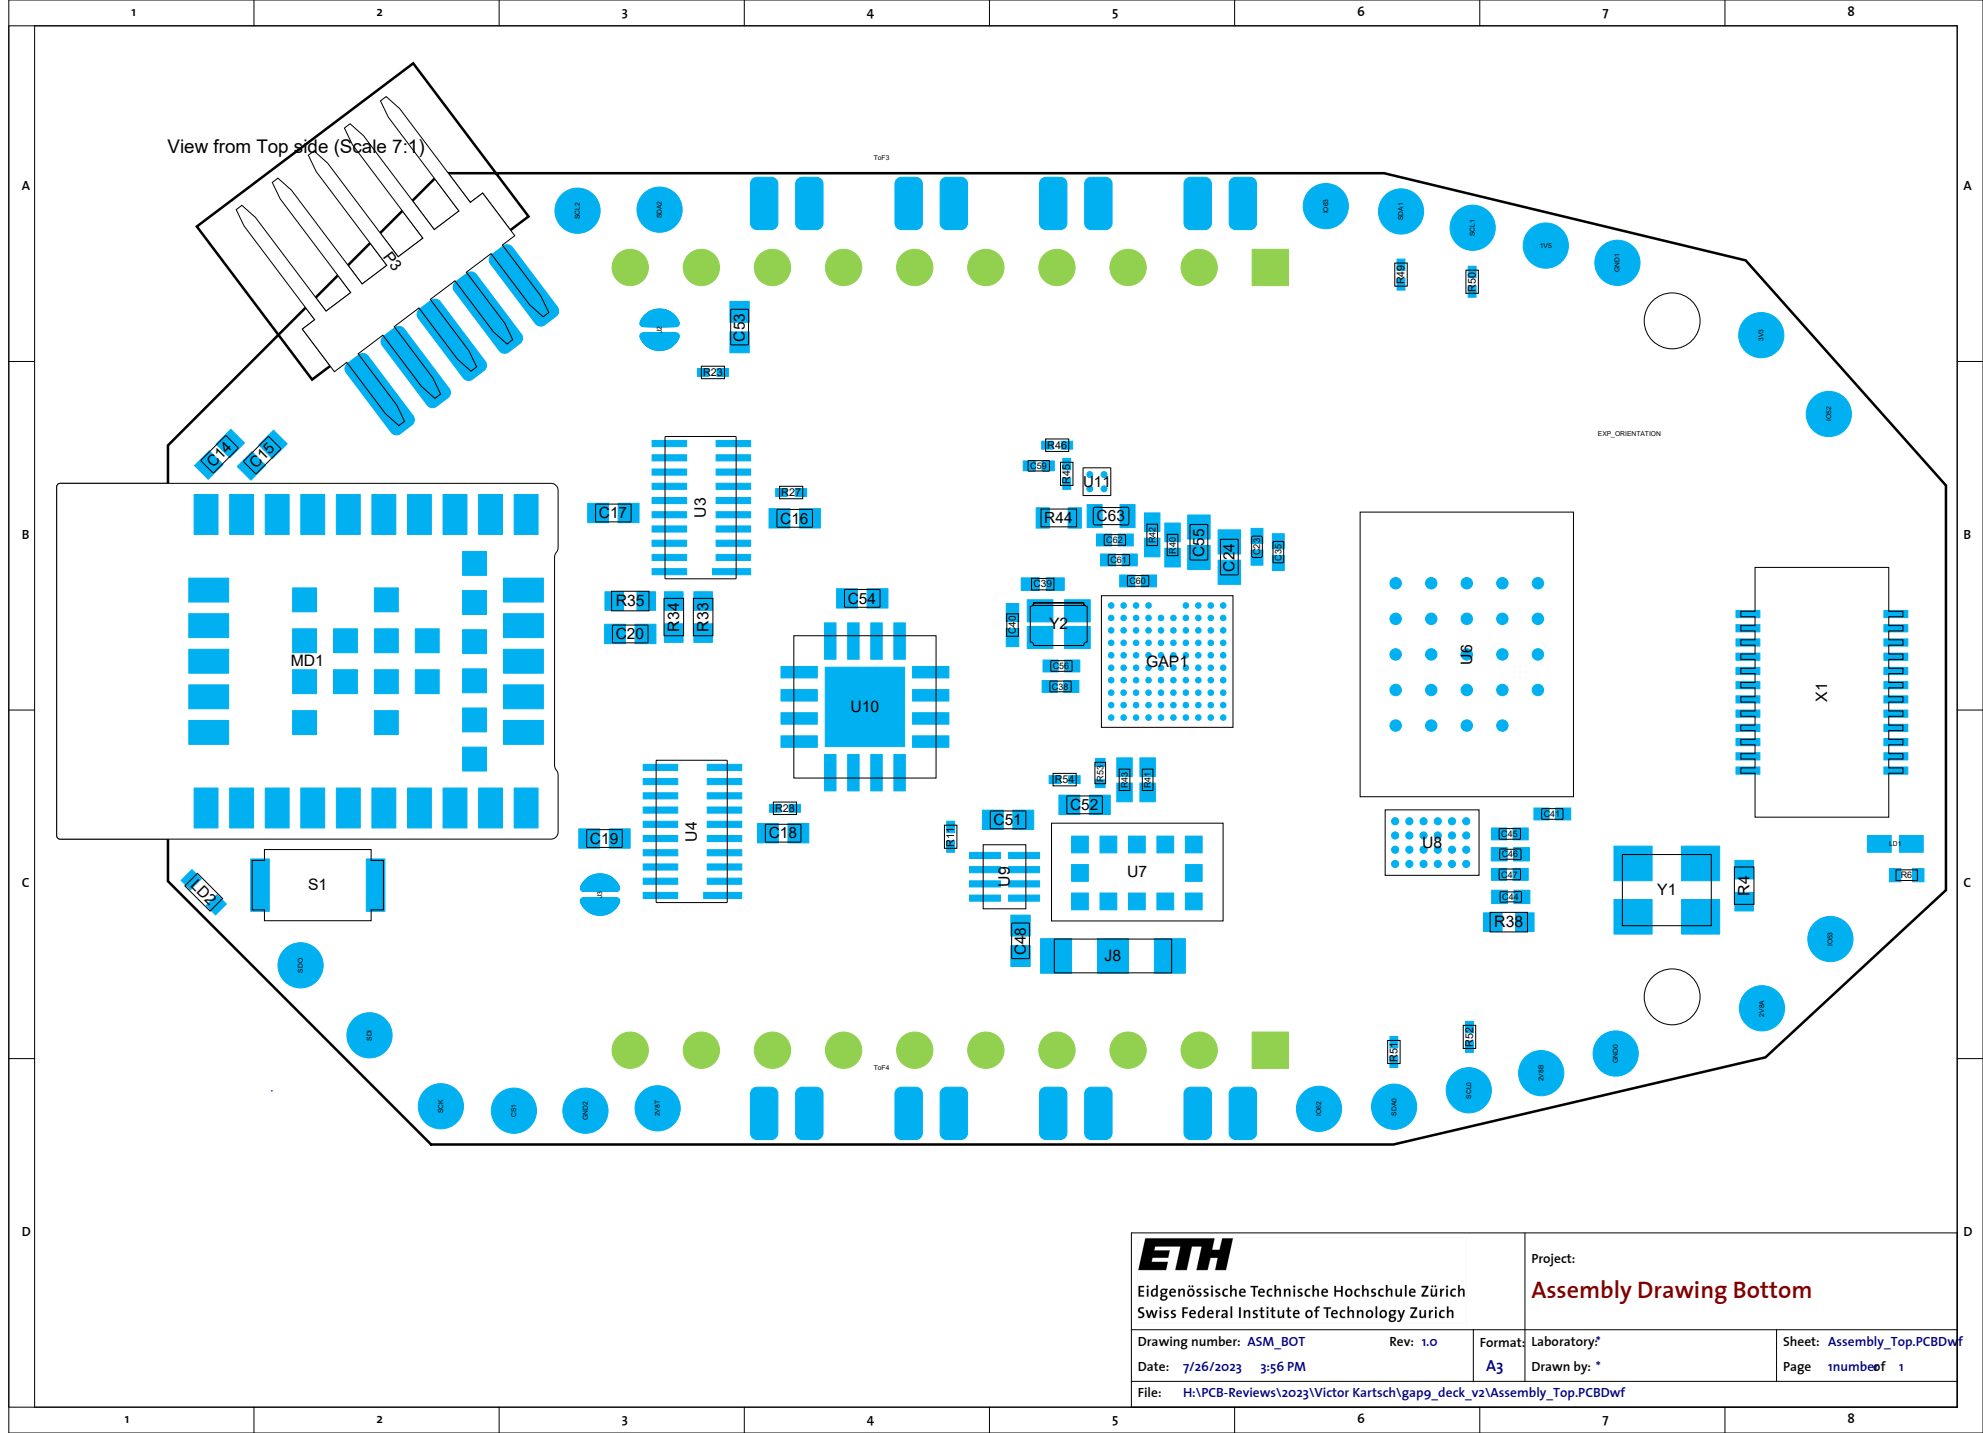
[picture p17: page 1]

View from Top side (Scale 7:1)

Project: Assembly Drawing Bottom

Drawing number: ASM_BOT Rev: 1.0 Date: 7/26/2023 3:56 PM | Format: A3 | Laboratory:* Drawn by: * | Sheet: Page 1numberof 1

H:\PCB-Reviews\2023\Victor Kartsch\gap9_deck_v2\Assembly_Top.PCBDwf
File:

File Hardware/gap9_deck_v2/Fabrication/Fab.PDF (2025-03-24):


Project: Fabrication

Drawing number: FAB_2 Rev: 1.0 Date: 7/26/2023 3:56 PM | Format: A3 | Laboratory:* Drawn by: * | Sheet: Fabrication.PCBDwf Page 1numberof 1

H:\PCB-Reviews\2023\Victor Kartsch\gap9_deck_v2\Fabrication.PCBDwf


252 | 0.15mm | Plated | Via | (Mixed)
26 | 0.20mm | Plated | Via | (Mixed)
20 | 0.80mm | Plated | Pad | (Mixed)
2 | 1.60mm | Plated | Pad | c250h160m0mx0
300 Total

Drill Drawing View (Scale 4:1)

Symbol | Count | Hole Size | Plated | Via / Pad | Template

87 | 0.10mm | Plated | Via | v20h10m0
87 Total

42 | 0.10mm | Plated | Via | v20h10m0
42 Total

27 | 0.15mm | Plated | Via | v30h15m20
27 Total

25 | 0.10mm | Plated | Via | v20h10m0
25 Total

25 | 0.10mm | Plated | Via | v20h10m10mx0

Project: Fabrication

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

H:\PCB-Reviews\2023\Victor Kartsch\gap9_deck_v2\Fabrication.PCBDwf

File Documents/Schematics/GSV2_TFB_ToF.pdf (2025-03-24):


Project: GAP9Shield: TOFs

Drawing number: 1 Rev: v1.0 Date: 3/24/2025 2:25:25 PM | Format: A3 | Laboratory: Integrated Systems Laboratory Drawn by: Hanna Müller and VictorKartsch | Sheet: 01_ToF.SchDoc Page 1 of 1

C:\deleteme\gap9-shield\Hardware\ToF-FrontBack\01_ToF.SchDoc


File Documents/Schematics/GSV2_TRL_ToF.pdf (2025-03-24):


Project: GAP9Shield: TOFs

Drawing number: 1 Rev: v1.0 Date: 3/24/2025 2:27:35 PM | Format: A3 | Laboratory: Integrated Systems Laboratory Drawn by: Hanna Müller and VictorKartsch | Sheet: 01_ToF.SchDoc Page 1 of 1

C:\deleteme\gap9-shield\Hardware\ToF-LeftRight\01_ToF.SchDoc


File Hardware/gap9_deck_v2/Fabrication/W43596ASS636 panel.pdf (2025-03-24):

c4286ebc06a0; biaozhu
